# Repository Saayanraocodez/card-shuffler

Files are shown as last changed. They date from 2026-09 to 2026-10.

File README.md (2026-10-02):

# Open card shuffler — 54-slot wheel, 3D-printed, battery powered

A one-button shuffler for one 52–54 card poker deck. Cards are fed one at a
time into a uniformly random empty slot of a 54-slot wheel, then the wheel
is emptied in slot order into a chute. Assigning each card to a random
empty slot is the Fisher–Yates algorithm, so every ordering of the deck is
exactly equally likely when the mechanism does what it is told, and the
firmware checks each insertion with a sensor so that the ways it can fail
are logged, not hidden.

**Status: complete design, unbuilt.** Nothing here has been printed, wired
or tested on hardware. Every performance number is an estimate and is
labelled as such. This machine is not proven, not production-ready and not
guaranteed uniformly random; the validation plan says how to earn those
words.

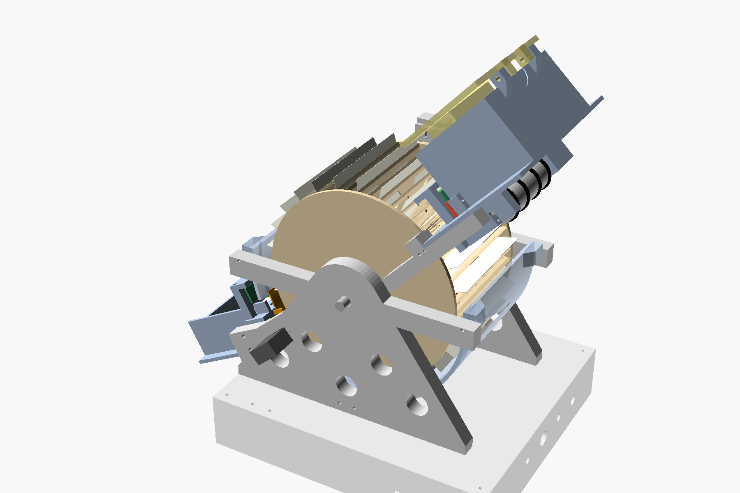
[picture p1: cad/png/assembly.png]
assembly


The first iteration (elevator + separator blades, exact but slower) is kept
complete in `archive/v1-elevator-insertion/`.

## What is here

| Deliverable | Where |
|---|---|
| Mechanism comparison and selection | `docs/01-mechanism-selection.md` |
| Mathematics: uniformity proof, RNG, fault analysis, riffle theory, validation plan | `docs/02-mathematics.md` |
| Simulation and results | `simulation/shuffle_sim.py`, `simulation/results/` |
| Bit-exact RNG reference, physical-test analysis | `simulation/rng_reference.py`, `simulation/analyze_physical.py` |
| Parametric CAD, 24 STL files (print list in `cad/print-settings.md`), views, collision and printability checks | `cad/params.scad`, `cad/shuffler.scad`, `cad/stl/`, `cad/png/`, `cad/check_clearance.sh`, `cad/check_printability.py` |
| Mechanical design document | `docs/03-mechanical-design.md`, `cad/print-settings.md` |
| Electronics, battery, wiring, pins | `docs/04-electronics.md`, `electronics/wiring-diagram.svg` |
| Bill of materials | `docs/05-bom.md`, `electronics/bom.csv` |
| Firmware (ESP32, Arduino) | `firmware/` |
| Assembly, calibration, first use | `docs/06-assembly.md` |
| Operation, maintenance, troubleshooting | `docs/07-operation-maintenance-troubleshooting.md` |
| Verification checklist, prototype plan | `docs/08-verification-checklist.md`, `docs/09-prototype-plan.md` |
| Gaps and unknowns | `docs/10-deliverables-and-gaps.md` |
| Diagrams | `docs/img/` |

## Headline numbers (estimates unless stated)

| | |
|---|---|
| Parts cost, excluding printing | ≈ $114 new; ≈ $96 with a parts drawer; ≈ $88 minimum |
| Cycle time, 52 cards | 40–45 s first build; 28–32 s tuned (target 30 s: within reach, not promised) |
| Randomness | exact uniform in the ideal model (proof §2.2); symmetric slot errors provably harmless with the firmware's map correction; biased errors measured by the machine's own log |
| Size | ≈ 298 × 231 mm footprint (under 12 × 12 in), ≈ 331 mm tall |
| Battery | 3S Li-ion 2200 mAh with BMS; ≈ 0.05 Wh per shuffle |
| Cards | 52–54, thickness 0.22–0.42 mm |

## Quick start for a builder

1. Read `docs/01` and `docs/03`.
2. Follow `docs/09-prototype-plan.md` (feeder first, wheel second).
3. Print with `cad/print-settings.md`, buy from `docs/05`, wire from
   `electronics/wiring-diagram.svg`, flash `firmware/`, calibrate with
   `docs/06` §6.7, verify with `docs/08`.

## Reproducing the analysis

```
pip install numpy scipy
python3 simulation/shuffle_sim.py --quick
python3 simulation/rng_reference.py --selftest
cd firmware/test_host && make run && ./syntax_check.sh
cd cad && ./render.sh && ./check_clearance.sh   # OpenSCAD 2021.01 + xvfb-run
pip install trimesh shapely scipy networkx rtree && python3 check_printability.py
```

## Licence

CC BY 4.0 (documentation, CAD), MIT (code). No warranty; see the safety
notes in `docs/07`.

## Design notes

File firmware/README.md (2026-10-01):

# Firmware (ESP32 DevKitC, Arduino framework) — wheel shuffler

```
shuffler/
  shuffler.ino     state machine: LOAD (random empty slot per card, verified by beam E), UNLOAD (slot order)
  config.h         pins, wheel geometry, speeds, timeouts, calibration record
  platform.*       core 2.x / 3.x shims, hardware RNG with the ADC entropy source
  hardware.*       wheel stepper, shutter servo, three N20 motors, beams B/E/S/X, index, battery, LED, buzzer
  motion.*         wheel home / goto / fin-to-entry / fin-to-exit / scan (every move refused while beam S or X
                   sees a card bridging the wheel); feeder with seat check and nudge; eject with double-card check
  rng.* sha256.* chacha20.*   entropy → SHA-256 → ChaCha20 → rejection sampling (portable)
  shuffle_core.*   empty-slot assignment + output prediction (pure, host-tested)
  storage.*        calibration in NVS
  cli.cpp          serial console (115200): `help`
test_host/         make run (bit-exact test vs simulation/rng_reference.py); ./syntax_check.sh (Arduino mock)
platformio.ini     pio run -e esp32dev
```

## Status

The platform-independent core is unit-tested and bit-exact with the Python
reference. The hardware modules were syntax-checked with `g++` against a
minimal Arduino mock; they have **not** been compiled with the real ESP32
core (toolchain download blocked in the authoring environment). Expect
first-compile fixes and tune every timeout and PWM on hardware.

## Bring-up (see docs/06 §6.7)

Set the TMC2208 Vref to ≈ 1.4 V first (the wheel accelerates at 5000°/s²).
`bat` → `cal vbat`; `beams` → `cal beams`; `home`; `entry 0` + straight edge →
`cal home`; `shutter open/close` → `cal shutter`; `feed` with `entry k`;
`cal entry`; `exit k` + `eject` → `cal exit`; `test fixed 1` + button →
`analyze_physical.py --compare`; `last` → `analyze_physical.py --log`.

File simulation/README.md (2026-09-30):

# Simulation and validation tools

Requirements: Python 3.9+, numpy (scipy optional for exact chi-square p-values).

| File | Purpose |
|---|---|
| `shuffle_sim.py` | Models: exact wheel assignment, wheel neighbour-slot faults (uncorrected and sensor-corrected, symmetric and biased), the archived v1 insertion model and its faults, GSR riffles, a two-hopper riffle machine, bin/shelf shufflers; the statistical test battery; exact Bayer–Diaconis table; small-n total variation. `--quick` ≈ 1 min; `--bd-table` theory only. |
| `rng_reference.py` | Bit-exact reference of the firmware RNG pipeline; `--selftest` prints the test-key slot assignment the firmware's `test ref` must reproduce. |
| `analyze_physical.py` | `--log` (correction tally from the firmware's `last` lines), `--compare` (predicted vs actual deck), `--slots` (statistics on dumped assignments), `--decks` (statistics on recorded physical shuffles). |
| `results/` | Output of the runs quoted in `docs/02-mathematics.md`. |

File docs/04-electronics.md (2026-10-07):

# 4. Electronics and battery power

Wiring diagram: `electronics/wiring-diagram.svg`. BOM: `05-bom.md` /
`electronics/bom.csv`. Firmware: `firmware/shuffler/`. All currents and
energies are **estimates [EST]**.

## 4.1 Architecture

```
 3S Li-ion pack (BMS) ─ fuse 3 A ─ switch ─┬─ VBAT (9.0–12.6 V) ─► TMC2208 ─► NEMA 17 (wheel)
 charge jack ── pack terminals             │                    └► 100k/33k divider ─► GPIO39
                                           └─ buck 5.0 V / 3 A ─┬─► ESP32 DevKitC (VIN)
                                                                ├─► DRV8833 #1 ─► N20 feed, N20 entry nip
                                                                ├─► DRV8833 #2 ─► N20 exit nip
                                                                ├─► MG90S shutter servo
                                                                ├─► 4 × IR LED (NPN switched) + index LED (always on)
                                                                └─► WS2812B
 Sensors (3V3): 4 phototransistors ─► GPIO34/35/32/36 (B, E, S, X); index phototransistor ─► GPIO19; button ─► GPIO21
```

## 4.2 Components

| Function | Part | Notes |
|---|---|---|
| Controller | ESP32 DevKitC V4 (WROOM-32, 30 pins) | hardware RNG, LEDC PWM, ADC1, USB serial |
| Wheel driver | TMC2208 stepstick, standalone, 1/16 | Vref ≈ 1.4 V ≈ 1.0 A RMS on the common 0.11 Ω-sense modules (I_RMS ≈ 0.71 × Vref; check your module); heatsink fitted. A4988 works from a 3S pack |
| Wheel motor | NEMA 17, 1.5–1.7 A class, 40 mm | direct drive through a 5→8 mm coupler onto the M8 rod |
| DC drivers | 2 × DRV8833 modules | 3 channels used |
| Feed roller, entry nip, exit nip | 3 × N20 6 V 300 rpm | feed at ~60 % PWM, nips at ~85–90 % |
| Shutter | MG90S | ±50° swing through an M2 pin |
| Sensors | 5 × 3 mm 940 nm IR LED + phototransistor: beams B (gate), E (card in slot), S (card seated), X (exit), and the index beam | B, E, S, X are read LED-on minus LED-off. E and S run 116 mm tower to tower, so their LEDs get 68 Ω. The index LED is always on |
| Battery | 3S Li-ion 11.1 V 2200–2600 mAh with BMS | 12.6 V 1 A barrel charger |
| 5 V rail | MP1584/LM2596 buck, ≥ 3 A | |
| Indicators | WS2812B pixel, passive piezo | |

## 4.3 ESP32 pin assignment

| GPIO | Name | Dir | Connected to |
|---|---|---|---|
| 25 / 26 / 27 | STEP / DIR / EN | out | TMC2208 (EN active low) |
| 16 / 17 | FEED_IN1 (PWM) / IN2 | out | DRV8833 #1 AIN1/AIN2 → feed roller |
| 4 / 5 | NIPE_IN1 (PWM) / IN2 | out | DRV8833 #1 BIN1/BIN2 → entry nip |
| 15 / 2 | NIPX_IN1 (PWM) / IN2 | out | DRV8833 #2 AIN1/AIN2 → exit nip (strapping pins: the driver inputs do not pull them; keep the DRV asleep at boot) |
| 23 | DRV_SLEEP | out | both DRV8833 nSLEEP |
| 18 | SERVO | out (50 Hz) | shutter MG90S |
| 13 | IR_LED_EN | out | NPN base via 1 kΩ (three emitters) |
| 14 | PIXEL | out | WS2812B DIN via 330 Ω |
| 33 | BUZZER | out (tone) | piezo via 100 Ω |
| 34 / 35 / 32 / 36 | BEAM_B / BEAM_E / BEAM_S / BEAM_X | ADC1 | phototransistor emitters, 10 kΩ pull-downs |
| 39 | VBAT | ADC1 | 100 kΩ / 33 kΩ divider, 100 nF |
| 19 | INDEX | in | index phototransistor emitter, 10 kΩ pull-down (LOW when the tab blocks the beam) |
| 21 | BUTTON | in (pull-up) | start button to GND |
| 22 | DECK_SENSE | in (opt.) | TCRT5000 DO |
| 12, 0 | avoid | | GPIO12 must not be pulled high at boot |

## 4.4 Power budget [EST]

Assumptions: 3S at 11.1 V, buck 85 %, wheel driver disabled between moves
(the shuffle is 40 s: 26 s loading with the wheel moving ~50 % of the time,
12 s unloading with the wheel moving ~40 %).

| Load | Condition | Power | Duty | Average |
|---|---|---|---|---|
| ESP32 | always | 0.40 W | 100 % | 0.40 W |
| IR LEDs (4 pulsed, ~160 mA while on) + index LED | polling | 0.45 W | 100 % | 0.45 W |
| Pixel | | 0.10 W | 100 % | 0.10 W |
| NEMA 17 at 1.0 A RMS | moving | 5.5 W | 45 % | 2.5 W |
| N20 feed + entry nip | 0.5 s per card during loading | 1.5 W | 45 % (of the load phase ≈ 30 % of total) | 0.45 W |
| N20 exit nip | 0.15 s per card during unloading | 0.75 W | 20 % of total | 0.15 W |
| Servo | holding open during unload | 0.5 W | 30 % | 0.15 W |
| **Total from the pack while shuffling** | | | | **≈ 4.7 W** |
| Idle | | | | ≈ 0.8 W |

* Energy per 40 s shuffle ≈ 190 J ≈ **0.05 Wh**.
* Usable pack energy ≈ 19.5 Wh → **≈ 390 shuffles** back-to-back (upper bound).
* A 4-hour evening with 40 shuffles ≈ 2 + 3.2 = 5.2 Wh → about 3–4 evenings per charge.

## 4.5 Peak and stall currents [EST]

| Item | Peak / stall |
|---|---|
| NEMA 17 (driver-limited) | 1.0 A RMS, 1.4 A peak per phase; at a 12 V bus ≈ 0.6 A from the pack during acceleration. Needed: ≈ 13 N·cm at 5000°/s²; a 17HS4401 gives ≈ 25–30 N·cm at 1 A, so the margin is about 2× |
| MG90S | ≈ 0.7 A at 5 V stall (shutter travel is unobstructed) |
| N20 ×3 | ≈ 0.8–1.0 A each at 5 V stall; at most two run at once |
| Worst case simultaneous | ≈ 5.5 W + 5 V × 2.7 A / 0.85 ≈ 21 W ≈ **2 A from the pack** |

3 A fuse, 3 A buck, pack BMS ≥ 5 A.

## 4.6 Battery, charging, low-battery behaviour

Unchanged from v1 (`archive/v1-elevator-insertion/docs/04-electronics.md`
§4.6):
* **Pack:** 3S1P 18650 pack with integrated protection, Velcro-strapped on
  a foam pad in the front base box.
* **Charging:** 5.5 × 2.1 mm charge jack wired to the pack terminals,
  upstream of the switch.
* **Thresholds:** warning below 9.9 V, refuse to start below 9.6 V, abort
  below 9.3 V. When the firmware aborts mid-load, it finishes the current
  card and unloads the cards already in the wheel into the chute. The
  remaining cards stay in the hopper. Charge, put all cards back in the
  hopper and shuffle again.
* **Options:** the USB-C PD power-bank option and the 2S option are as in
  v1.

## 4.7 Safety and shutdown

* The wheel cannot drop anything on power loss: cards sit in slots, the
  shroud holds the lower half, and the shutter's servo is unpowered when
  idle with the shutter closed by its own friction (add the return spring
  post if the shutter drifts).
* Any jam stops all motors within one sensor poll and waits for the
  button. Holding the button for 3 s runs "unload all": close the
  shutter, home, scan, bring the first occupied slot to the exit, open
  the shutter, then empty every occupied slot into the chute.
* **Interlock:** the wheel refuses to move while beam S (a card bridging
  the feeder and a slot) or beam X (a card in the exit nip) is blocked. A
  half-inserted card can therefore never be dragged into the frame.
* The wheel is enclosed by the towers, shroud, feeder and chute; the open
  areas are the hopper (under the lid) and the chute. Fingers cannot reach
  the wheel rim except through the chute end when the shutter is open; the
  wheel moves at up to 360°/s but has little inertia and the stepper stalls
  at about 20 N·cm.

## 4.8 Perfboard

70 × 50 mm perfboard: ESP32 on female headers, TMC2208 and two DRV8833 on
female headers, buck module, NPN with a 470 Ω base resistor, LED resistors
(150 Ω for B and X, 68 Ω for E and S, 330 Ω for the always-on index LED),
five 10 kΩ pull-downs, divider, capacitors (100 µF on TMC VM, 100 µF on
each DRV VM, 470 µF on 5 V), JST-XH headers J1–J17 (see the wiring
diagram). Mount in the front base box with
the ESP32's USB reachable through the side cut-out.

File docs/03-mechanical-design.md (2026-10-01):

# 3. Mechanical design and printable parts

Source of truth: `cad/params.scad` (every dimension) and `cad/shuffler.scad`
(every part, assembly, exploded and section views). STLs are in `cad/stl/`
and views in `cad/png/`. Both are regenerated by `cad/render.sh` (OpenSCAD
2021.01). `cad/check_clearance.sh` checks that no fixed part enters the
volume swept by the wheel and its cards, and that neighbouring parts do not
overlap (17 checks, all passing).

| View | File |
|---|---|
| Assembly | `cad/png/assembly.png` |
| Exploded | `cad/png/exploded.png` |
| Section at the centreline | `cad/png/section.png`, annotated `docs/img/mechanism-section.svg` |
| Front (looking along the axis) | `cad/png/front.png` |
| Wheel module exploded | `cad/png/wheel_exploded.png` |
| Feeder / exit modules exploded | `cad/png/feeder_exploded.png`, `cad/png/exit_exploded.png` |
| Load / unload sequence | `docs/img/insertion-sequence.svg` |

## 3.1 Frame, layout and the clearance rule

The wheel axis is horizontal (Y). Angles are measured in the vertical XZ
plane from +X (3 o'clock), counter-clockwise. Fin k is a radial plate whose
counter-clockwise face lies on the radial plane at (wheel angle + k · 6.667°).
Slot k is the space between fin k and fin k+1.

**Clearance rule.** Whenever the wheel turns, the seated cards sweep every
point with radius ≤ 85.5 mm and |Y| ≤ 46 mm, including card play in the cage.
The discs sweep r ≤ 77.5 at |Y| 46–49, and the index tab sweeps r 66–76 at
Y 49–53. Nothing fixed may enter these volumes, with at least 0.4 mm to
spare. Every fixed part at the entry and exit therefore starts outside
r 86.

| | mm |
|---|---|
| Footprint, overall | ≈ 298 × 231 (11.7 × 9.1 in, under the 12 × 12 in limit) |
| Base boxes | 233 × 210 × 45 |
| Height | ≈ 331 (axis 145 above the table, hopper lid top 186 above the axis) |
| Wheel outer diameter (fin tips / discs) | 155 |
| Shroud outer diameter | 183 |
| Mass, printed parts | ≈ 1.25 kg [EST] (wheel ≈ 375 g) |

## 3.2 The wheel

| Feature | Value | Reason |
|---|---|---|
| Slots | 54 | 52-card deck plus jokers; two slots stay empty |
| Hub tube outer radius (card stop) | 22 | smallest hub that keeps the slot at the hub ≥ 1.1 mm |
| Seated card: inner / outer edge | 22 / 85.5 | card 63.5 mm radial |
| Fin tips and disc radius | 77.5 | cards overhang 8 mm; the entry beam sees the overhang |
| Fin thickness | 1.4, chamfered to a point over the last 2.5 mm | an incoming card rides onto the fin face instead of hitting its end |
| Slot width | 1.16 at the hub, 7.6 at the tip | funnel |
| Fin windows | 17 × 30 and 19 × 30 mm per fin, pointed at the +Y end | lighter fins; the points let the window tops print without bridging. Inertia ≈ 1.45 × 10⁻³ kg·m² with cards [EST] |
| Discs | 3 mm. −Y disc solid (it is the first layers on the bed); +Y disc spoked, ring r 62–77.5 | |
| Hub | tube r 20–22 with a bore tube and 6 ribs inside | the +Y disc bridges ≤ 14 mm between the ribs |
| Index tab | +Y disc face, r 66–76, Y 49–53, at 90° | inside the rim, so it never crosses the entry beams |
| Bore | 8.6 for an M8 threaded rod, clamped by nyloc nuts | +Y boss on the wheel; the −Y boss is the separate `hub_spacer` |

Printing: axis vertical, the solid −Y disc on the bed, 104 mm tall, about
24 h, PETG. The top disc bridges the ≤ 7.6 mm slot widths.

## 3.3 Retention: shroud and shutter

In the lower half, gravity pulls cards outward. A fixed shroud stops them
after 3 mm of travel: inner radius 88.5, 3 mm thick, in two segments from
172° to 270° and from 270° to 368°. It runs from tower face to tower face
(116 mm), so each segment prints standing on a full edge. The −Y edge is
cut back to 92 mm wide where the shutter's drive tab travels (202°–236.5°).
Across the exit window only a strap at |Y| 47–58 remains, outside the
card width. The card edge then slides
on smooth PETG as the wheel turns.

The exit window (202°–214°) is closed during loading by a **shutter blade
on the inside of the shroud**. The blade is 1.2 mm thick at r 87.0–88.2 and
spans 199.4°–216.6°. Its ends taper to 0.4 mm, so a card edge riding on the
shroud ramps onto the blade and off again, and no edge is exposed for a
card to catch. To open, an MG90S servo in a pocket in the −Y tower slides
the blade 17.5° counter-clockwise along the shroud's inner surface. The
servo drives through an M2 pin on an 18 mm horn into a radial slot in the
blade's drive tab, which sits beside the shroud end at |Y| 46.5–48.5,
outside the card width. Gravity keeps the blade against the shroud
everywhere it travels. With the window open, a card at 208° slides out
under 0.47 g into the exit nip.

## 3.4 Feeder (entry at 50°)

Cards travel along their 63.5 mm edge. The hopper interior is 65 (radial)
by 91 (axial), and its floor is the plane of the entry fin, 46.7° from
horizontal. The deck slides against the gate under 0.73 g, so lid ballast
matters only for the last cards.

| Feature | r (mm) | Note |
|---|---|---|
| Beam E, "card in the slot" | 81.5 | oblique, from the +Y tower (4 mm above the card plane) to the −Y tower (4 mm below). It crosses the plane of the card in the target slot near the centre, so that card blocks it completely. Neighbour cards are 9.5 mm away |
| Seated card outer edge | 85.5 | |
| Beam S, "card seated" | 86.8 | oblique like beam E. It is blocked only while a card still bridges the plate and the slot |
| Entry nip axis (Ø16 roller, 4 O-rings 10 × 3) | 96 | nearest point r 88.3; the deck plate starts at the nip (r 88.5) |
| Idler wheels | over the outer O-rings, Y ±27 | spring-loaded arm, pivot at r 107.75; pen springs bear on a `spring_bar` screwed across the pivot posts |
| Beam B (gate beam) | 106.5 | detector in the idler arm's boss, emitter in the plate |
| Gate lip | 118 | slotted clamp, feeler gauge, 0.45 mm nominal |
| Feed roller axis (Ø27, 4 O-rings 20 × 3.5) | 129.5 | crown 0.7 mm above the floor |
| Hopper | 118–183 | back wall to 186; lid hinge on the back wall |

The nip pushes the card until 10.5 mm before the hub. The card bridges
11 mm from the nip to the fin tips, then slides down the fin face under
0.73 g and stops on the hub tube. The firmware sets the fin 0.3° below the
card plane, so the card meets the fin's chamfered lead-in rather than its
end. The rollers are 64 mm long, so each N20 motor fits between the roller
end and the tower (Y 32.5–56.5). The next card is pre-staged 10 mm past the
gate. The gate geometry and thickness range are unchanged: t_max < gap <
2 t_min, adjustable 0.30–0.60 mm.

## 3.5 Exit (205°) and chute

| Feature | r (mm) | Note |
|---|---|---|
| Shroud window | 202°–214° | covered by the shutter blade while loading |
| Exit nip axis (Ø16 roller) | 100.5 | everything at the exit starts at local r ≥ 95.5, clear of the shutter tab |
| Beam X | 111 | detector in the exit idler arm (the same part as the entry arm) |
| Chute floor | 109.5–182.5, 28 mm below the exit plane | inclined 28°; a 54-card thick deck stays below the exit plane. It sits between the towers (\|Y\| ≤ 57.5) |
| Chute mounting | nip housing at r 111 | 2 horizontal M3 × 20 per side, through the towers' chute cheeks into the housing |
| End wall | 182.5 | felt-lined; the pile starts 8 mm past beam X |

The deck forms against the end wall. The chute end overhangs the rear base
and clears the table by about 30 mm.

## 3.6 Towers, drive, base

* **Towers.** Two 12 mm plates at |Y| = 58–70, printed flat with the outer
  face down (213 × 198 mm, fits a 220 mm bed). Each has:
  * a 608ZZ bearing pocket;
  * a foot on the base;
  * a crossbar carrying the shroud tabs;
  * an arm under the feeder deck with two vertical M3 holes (the deck
    screws down into it);
  * a chute cheek with two horizontal holes (the chute screws to it from
    outside);
  * a 4 mm inner-face boss holding the beam E and beam S emitters (+Y) or
    detectors (−Y).

  The +Y tower also has a post at 12 o'clock for the index bracket and
  four counterbored holes for the motor bolts. The separate `motor_mount`
  (a hollow Ø50 × 28 standoff holding the coupler) sits on its outer face;
  four M3 × 40 bolts go from the tower's inner face through both into the
  NEMA 17. The −Y tower has the shutter servo pocket and horn recess.
* **Drive.** NEMA 17 → 5–8 mm flexible coupler → M8 threaded rod, cut to
  165 mm, clamped to the wheel with nyloc nuts. The rod turns in the
  bearings: wrap one layer of tape on the thread at each bearing seat so it
  does not rattle. Direct drive, 3200 µsteps per revolution, 0.11° per
  microstep.
* **Base.** Front and rear boxes (193 and 40 mm long, 210 wide, 45 tall)
  with bottom covers. The tower feet screw to the base top, so the axis is
  100 mm above it. The battery and perfboard go inside, and the panel is on
  the front face.

## 3.7 Printed parts

The full list, with quantities, sizes, orientation, settings and
post-processing, is `cad/print-settings.md`: **24 STL files, 30 printed
pieces** (2 × `roller_nip`, 2 × `idler_arm`, 4 × `idler_wheel`,
2 × `spring_bar`). Every STL rests on Z = 0 in its print orientation, and
`cad/check_printability.py` confirms that each one is a closed solid that
fits a 220 mm bed and prints without supports. Total ≈ 1.25 kg [EST]
(≈ 0.9 kg PETG, ≈ 0.35 kg PLA).

## 3.8 Tolerances and adjustment points

| Fit | Nominal | Adjustment |
|---|---|---|
| Wheel position at the entry | ±0.7° (±1 mm at the mouth) | `cal home`, `cal entry` (default −0.3°), `cal exit` |
| Slot mouth | 7.6 mm at the tip, 1.16 at the hub | none; the funnel self-guides |
| Seated card edge to nearest fixed part | ≥ 1.3 mm (beam S line) | none |
| Card in the cage (axial) | 92 for 88.9 | none |
| Shroud to card edge | 3 mm | shim the shroud tabs if cards rub |
| Shutter blade to shroud | 0.3 mm | sand the blade's outer face |
| Gate gap | 0.45 | feeler gauge (the critical adjustment) |
| Idler wheels to roller O-rings | O-ring contact at the card plane | pen springs; add a washer for more force |
| Beam thresholds | auto | `cal beams` |
| Bearing pockets | 22.2 for 608ZZ | press fit |

Print variation is absorbed by the funnel-shaped slot mouths, the firmware
trims and the feeler-gauge gate. The only printed dimension that affects
randomness is the fin pitch. That is a division of the circle and cannot
drift.

## 3.9 Card protection

| Risk | Response |
|---|---|
| Scratches | rolling contact in the nips; cards slide face-on over smooth fins; rounded gate lip; felt on the chute end wall and under the lid boss |
| Edge wear | the hub stop is a 2 mm PETG wall; in the lower half the edges ride on the shroud and on the tapered shutter; a felt strip inside the shroud is an optional upgrade |
| Bent corners | straight radial entry onto a chamfered fin; the wheel cannot turn while beam S or beam X sees a card half in a slot |
| Excessive pressure | nips about 2 N; lid about 0.6 N |
| Exposed faces | face down under the lid; between fins inside the cage; only the top card's back shows in the chute |
| Double feed | gate at 1.3–1.5 × card thickness; beam-B and beam-X block-time checks; end count |
| Cards flying out | shroud and shutter in the lower half; gravity and a 360°/s speed limit in the open upper half |

## 3.10 Things a builder may want to change

`entry_slot_ang` (steeper hopper), `exit_slot_ang` (steeper exit, longer
chute), `fin_t`, `n_slots` (keep `N_SLOTS_HW` in the firmware equal),
`roller_len` (the N20 must still fit inside the towers). After any change,
run `cad/check_clearance.sh`.

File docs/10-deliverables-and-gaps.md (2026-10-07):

# 10. Deliverables, what could not be produced, open unknowns

## 10.1 Delivered

| Requested | Delivered |
|---|---|
| Mechanism comparison, selection, tradeoffs | `01-mechanism-selection.md` (wheel selected; v1 elevator-insertion and the two-well variant compared) |
| Honest cycle-time estimate | `01` §1.6: 40–45 s first build, 28–32 s tuned |
| Mathematics: proofs, RNG, fault analysis, riffle theory, validation plan | `02-mathematics.md` |
| Simulation code and results | `simulation/shuffle_sim.py`, `simulation/results/` (wheel, corrected/uncorrected faults, v1 faults, riffles, bins) |
| Dimensioned mechanical design, parametric CAD, printable files, exploded views, print settings, tolerances | `03-mechanical-design.md`, `cad/params.scad`, `cad/shuffler.scad`, 24 STL files in `cad/stl/`, views in `cad/png/`, print list `cad/print-settings.md`, collision checks `cad/check_clearance.sh`, print checks `cad/check_printability.py` |
| Electronics, battery, wiring, BOM | `04-electronics.md`, `electronics/wiring-diagram.svg`, `05-bom.md`, `electronics/bom.csv` |
| Complete firmware | `firmware/shuffler/` (RNG core host-tested bit-exact; hardware modules syntax-checked against a mock) |
| Assembly, calibration, first-use checks | `06-assembly.md` |
| Operation, maintenance, troubleshooting | `07-…md` |
| Verification checklist, prototype plan | `08`, `09` |
| Previous design for comparison | `archive/v1-elevator-insertion/` (complete, self-contained) |

## 10.2 Not produced, or produced with limits

* **No physical build, no measurements.** Every [EST] value is an estimate.
  What can be claimed today: the algorithm is uniform (proof); the firmware
  RNG core is bit-exact with the reference and passes its tests; the CAD
  passes 17 automated collision checks against the wheel's swept volume
  and between neighbouring parts; the fault models are simulated. What cannot: feeding reliability,
  slot-entry and slide-out reliability, the cycle time, battery life.
* **ESP32 compile.** The Espressif toolchain could not be downloaded in the
  authoring environment (the proxy blocks the PlatformIO registry, GitHub
  archives and dl.espressif.com). The hardware modules were syntax-checked
  with `g++` against a minimal Arduino mock (`firmware/test_host/mock/`,
  `firmware/test_host/syntax_check.sh`), which catches typos and type errors but not API
  mismatches with the real core. Budget an hour for first-compile fixes.
* **3MF, STEP, PCB files** not generated (OpenSCAD 2021 exports STL).
* **Supplier verification** partial: main parts checked against listings in
  September 2026 (ESP32, TMC2208, MG90S, N20, DRV8833, chargers, IR parts,
  lead-screw kits with couplers); the 3S pack, NEMA 17 single price, index
  module and small hardware are typical prices.
* **Renders** are OpenSCAD previews, not photographs.

## 10.3 Critical unknowns to retire in Stages 1–3

1. Single-card separation with a lip gate on a 50° hopper (the deck presses
   harder on the gate than in v1).
2. Card entry into the tapered slot at 50°: whether cards ever stop short or
   bounce back, and the symmetric/biased split of neighbour-slot errors.
3. Card slide-out at 28° below horizontal into the exit nip; cards clinging
   to the fin by static.
4. Card edges riding on the shroud in the lower half: wear over hundreds of
   decks.
5. Wheel index time and stall margin with the real wheel mass.
6. `bootloader_random_enable()` interaction with `analogRead` on the
   installed core (firmware re-initialises the ADC after seeding).
7. The inner shutter blade (1.2 mm PETG) sliding on the shroud: friction,
   and whether card edges ride its 0.8 mm ramps smoothly.
8. The oblique beams E and S: signal margin over 116 mm with a 1.2 mm
   aperture, and how cleanly beam S separates "seated" (edge at r 85.5)
   from "bridging" (card across r 86.8).

## 10.4 Review log (design review after the wheel redesign)

Mistakes found and fixed in the review:

* **Speed:** firmware acceleration 900°/s² gave 0.6 s per index, not the
  0.25 s the docs claimed. It is now 5000°/s² at about 1 A RMS. The quoted
  torque had also been 10× too high.
* **Entry:** seated cards overlapped the feeder plate and the beam-E
  bridge by 3.5 mm. Every wheel move would have dragged cards into them.
  The plate now starts at the nip, and beams E and S run obliquely between
  the towers.
* **Exit:** the outside sliding shutter let cards drop 3.5 mm into the
  window and snag its edge. It is now a ramped blade on the inside of the
  shroud.
* **Feeder motors:** the entry N20 motors passed through the motor-side
  tower. The rollers are now 64 mm long and the motors fit inside.
* **Idlers:** the idler wheels missed the roller O-rings. They now sit over
  the outer O-rings.
* **Missing mounts:** beam B's detector had no mount; it is now in the
  idler arm's boss. The idler springs had nothing to push on; spring
  crossbars were added. The index bracket screws went into empty space
  above the tower; a post was added. The slotted index module could not
  straddle the tab; it is now a radial LED and phototransistor pair.
* **Pivot conflicts:** the gate block flange collided with the idler pivot.
  The gate moved 7 mm outward. The idler ears sat on the rails and could
  not pivot.
* **Mismatched holes:** the tower-to-deck and tower-to-chute screw holes
  were perpendicular to their mating holes.
* **Placement:** the mechanism was placed 45 mm too low, sinking into the
  base. The chute passed through the rear base box.
* **Footprint:** it was 320 mm, over the 12 in (305 mm) limit. It is now
  about 298 × 231 mm.
* **Firmware safety:** nothing stopped the wheel turning with a card half
  in a slot. There is now a beam S / beam X interlock on every move.
  There was also no check that the target slot was empty before feeding.
  The firmware now re-homes, then stops with ERROR 11. A failed eject
  carried on rotating; it now stops. The exit has a block-time double-card
  check.
* **Docs:** the low-battery abort description did not match the firmware.
* **Unload order:** the firmware opened the shutter before the first unload
  move, with the wheel still at the last entry position. Two cards rested
  over the window there and slid out against the stopped nip, unseen by
  beam X, and the move to slot 0 (up to 180°) swept 11–14 more cards across
  the open window, the snag the inner blade was meant to prevent. The
  wheel now brings the first occupied slot to the exit with the shutter
  closed, then opens it. With a full deck every later move carries only
  empty slots past the window. "Unload all" also closes the shutter before
  homing, since it can follow an ERROR 9 with the shutter still open. The
  bench test (6.5) and C8 (6.7) now move first and open second. Still
  open: on a wheel holding a few cards, a run of more than 27 empty slots
  makes the move to the next card take the short way back over the
  window, carrying any later card across it.

## 10.4.1 Print-readiness sweep

A slicer-style check (`cad/check_printability.py`: slices every STL at
0.2 mm and flags anything printed over air) and new mating-part collision
checks found:

* **Towers** printed standing on their 4 mm beam bosses, with the whole
  plate 4 mm in the air. They now print outer face down; the motor
  standoff became the separate `motor_mount`, bolted through with 4 × M3 ×
  40. A plate was added behind the beam boss, which overhung the tower edge.
* **Chute vs towers (assembly clash):** the chute floor ran through both
  tower plates (≈ 1.9 cm³ overlap), and one chute screw hole was sealed
  inside the tower. The floor now sits between the towers and screws to
  new tower cheeks from the side.
* **Wheel** printed on a hub boss, with the 155 mm disc 6 mm in the air.
  The −Y boss is now the separate `hub_spacer`, the −Y disc is solid, the
  hub has internal ribs, and the fin windows are pointed so their tops
  need no bridging. The wheel is heavier (≈ 375 g; inertia ≈ 1.45 × 10⁻³
  kg·m² with cards, ≈ 13 N·cm peak at 5000°/s²).
* **Shroud A** was cut in two by the exit window, and both shrouds stood
  on their tab feet only, with the arc 12 mm in the air. The arc now runs
  tower to tower, with a strap across the window and 45° tab gussets.
* **Feeder deck:** the hinge knuckles were loose, unattached bodies, and
  the middle one sat over the finger recess. The rails touched the gate
  bosses along a single edge, so the mesh was not watertight. The gate
  wall was a 91 mm bridge. Now there are two gusseted knuckles, window
  jambs, and three cut-away print ribs.
* **Spring crossbars** (deck and chute) were 110 mm bridges. They are now
  a separate `spring_bar`, ×2.
* **Lid** printed on its ballast box, with the plate overhanging it, and
  had a sealed cavity. The AA ballast now drops into pockets in the
  pressure boss, and the lid prints top face down.
* **Rollers** stood on their 4 mm stub axles; they now stand on the D-bore
  end. The **index bracket** printed with 7 mm ledges; it now prints back
  plate down. The **gate block's** top overhung its flange; it is tapered.
  The exit +Y rail hung over the motor pocket and was removed.
* **Counts:** 24 files, 30 pieces. The two nips use 2 × `roller_nip`, and
  the 2 × `idler_arm` carry 4 × `idler_wheel`. Filament is ≈ 1.25 kg, not
  900 g.

## 10.5 Environment record

* OpenSCAD 2021.01 rendered all 24 STL files with no warnings; `cad/check_clearance.sh`: 19 OK + 4 face contacts, no collisions (`cad/clearance.log`); `cad/check_printability.py`: all 24 parts OK (`cad/printability.log`).
* Simulation: `simulation/results/full_results.txt` and
  `simulation/results/corrected_runs.txt` (numpy 2.4, scipy 1.17).
* Host test: all pass. Syntax check: pass (two style warnings fixed).
* ESP32 compile: not possible here (see above).

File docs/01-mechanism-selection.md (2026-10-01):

# 1. Mechanism selection

This document compares the feasible ways to shuffle one 52–54 card poker
deck with a machine a hobbyist can print and wire, and explains why this
project uses a **54-slot wheel with random slot assignment** (a horizontal-
axis "rolodex" into which each card is pushed at a uniformly random empty
slot, then emptied in slot order). The first iteration of this project used
elevator-insertion with separator blades; it is kept in
`archive/v1-elevator-insertion/` and is compared below.

Everything here is a design analysis. Nothing has been built; the speed
and reliability numbers are engineering estimates and are labelled as such.

## 1.1 Requirements

| Requirement | Target |
|---|---|
| Deck | 52 cards, 54 if practical (poker size 63.5 × 88.9 mm) |
| Card thickness | 0.25–0.35 mm standard; 0.22–0.42 mm accepted (custom decks) |
| Operation | Load, one button, collect |
| Cycle time | < 30 s target; honest estimate required |
| Randomness | Measurably close to uniform over all 52! orders |
| Card safety | No scratches, bent corners, exposed faces |
| Power | Rechargeable protected battery |
| Cost | < $130 excluding printing |
| Size | Footprint under 12 × 12 in (305 × 305 mm); noise not a concern |

## 1.2 Candidates

**A. Two-hopper riffle machine** (the $20 consumer shuffler). Fast per pass
(3–5 s) but a machine riffle is far from the Gilbert–Shannon–Reeds model:
the cut is always near 26/26 and the rollers alternate almost perfectly, so
one pass leaves the deck with exactly 2 rising sequences. Seven or more
passes with manual re-splitting are needed; automating the re-split is the
hard part of any shuffler. Fails "one button".

**B. Random-bin (shelf) routing.** One feeder, a diverter, N bins stacked in
order. One pass is the inverse of an N-riffle; with N = 8 it takes 4 passes
to reach total-variation distance 0.01, and recombining the bins needs
either the user or a complex mechanism (Diaconis, Fulman & Holmes 2013
analysed a real 10-shelf casino machine and showed one pass is exploitable).

**C. Single-card random-gap insertion (elevator + blades)** — the archived
v1 design. Exact Fisher–Yates; every card needs its own serial
elevator/blade cycle of 1.0–1.4 s, and the blade must enter a chosen card
boundary to ±0.15 mm. Estimated 70–80 s per deck, 45–50 s tuned.

**D. Two parallel insertion wells** — v1 with a diverter and a second well.
Exactly uniform when the A/B assignment is exchangeable (proof in
`02-mathematics.md` §2.6). About 35–40 s, +$45, and the user stacks two half
decks.

**E. 54-slot wheel (random slot assignment) — selected.** A horizontal-axis
cage of 54 radial fins. Each card is pushed radially into a uniformly
chosen empty slot at the upper-right entry position (it slides down the fin
face under gravity and seats against the hub); when the hopper is empty a
shutter in the lower shroud opens and, as the wheel steps through the slots
in order, each card slides out under gravity into a roller nip that pulls
it into a tilted output chute. Assigning card i to a uniformly random empty
slot is the Fisher–Yates "draw from the remaining set" step, so the output
order (slot order) is exactly uniform (proof in `02-mathematics.md`).

| Criterion | A. Riffle | B. Bins | C. v1 insertion | D. Dual well | **E. Wheel** |
|---|---|---|---|---|---|
| Randomness per press | 1 | 2 | 5 | 5 | **5** |
| Speed (est.) | 5 (5 s ×7 manual) | 3 | 2 (70 s) | 3 (38 s) | **4 (35–45 s; ~30 s tuned)** |
| Precision demanded of the build | 4 | 4 | 1 (±0.15 mm) | 1 | **4 (±1 mm)** |
| Cost | 5 | 3 | 3 | 2 | **3** |
| Footprint | 4 | 3 | 4 | 2 | **3 (298 × 231 mm)** |
| Mechanical complexity | 4 | 2 | 3 | 2 | **4** |
| Card wear | 2 | 4 | 5 | 5 | **4** |
| One-button | 1 | 2 | 5 | 4 | **5** |
| **Weighted (randomness ×3, precision ×2, one-button ×2)** | 31 | 33 | 42 | 41 | **52** |

## 1.3 Why the wheel wins

* **No fine tolerance.** A slot mouth is 8 mm wide at the rim and tapers
  to 1.2 mm at the hub, so the wheel only has to be positioned to about
  ±1 mm (±0.7°). A direct-drive NEMA 17 at 1/16 microstepping resolves
  0.11°. The v1 design needed ±0.15 mm on a blade edge.
* **Exact algorithm, no gap opening.** Every card has its own slot; nothing
  is inserted into a stack.
* **Fewer actuators.** One stepper, three small DC motors (feed, entry nip,
  exit nip), one servo (shutter). v1 needed two servos, blades, a lead
  screw and guide rods.
* **Speed.** Loading is limited by the wheel index (average 90°, ≈0.25 s)
  plus the card push (≈0.25 s); unloading is a step-and-pull of 6.7° per
  card. Estimates in §1.6.
* **Self-checking.** A beam at the entry sees whether the card is in the
  slot just loaded; a card that lands one slot off is found by looking at
  the neighbours and the firmware corrects its map (§2.4 shows this keeps
  the output exactly uniform when the error is symmetric).

## 1.4 Architecture

```
                         hopper (deck face down, 50° slope, lid)
                        /  feed roller → gate → entry nip → beam E
                       /
      +Y tower ──── WHEEL: 54 radial fins, cards lie flat on a fin ──── −Y tower
      NEMA 17 ◄── M8 rod, 608 bearings ──►  index tab / sensor at 12 o'clock
                       \
   shroud (lower half)  \ exit window at 8 o'clock, servo shutter
                         \ exit nip → beam X → tilted chute (output deck)
```

* **Wheel module**: cage (Ø155 mm, 98 mm wide, hub tube Ø44, fins from
  r 22 to 77.5), two towers with 608 bearings on an M8 rod, NEMA 17 on the
  +Y tower through a flexible coupler, two shroud segments (lower half),
  a shutter blade sliding on the inside of the shroud, index bracket.
* **Feeder module** (at 50°): the v1 hopper turned so cards travel along
  their 63.5 mm edge. It has a feed roller (Ø27), an adjustable gate, an
  entry nip (Ø16) with spring idlers, gate beam B and a weighted lid. The
  "card in slot" beam E and "card seated" beam S run between the towers.
* **Exit module** (at 205°): exit window in the shroud, exit nip (Ø16)
  with idlers, exit beam X, and a chute inclined 28° with a felt-lined end
  wall. The deck is lifted out of the open chute.
* **Base**: two boxes (front/rear) holding the battery and the perfboard,
  with the panel (button, LED, switch, charge jack).
* **Controller**: ESP32 DevKitC; TMC2208 for the wheel, two DRV8833 for the
  three N20 motors; ChaCha20 DRBG seeded from the hardware RNG.

## 1.5 Card handling in the wheel

Cards lie flat on a fin at the entry (fin at 46.7° above horizontal). The
entry nip pushes each card until it is 10.5 mm from the hub, and the card
slides the rest of the way down the fin face under gravity. In the upper
half of the wheel, gravity keeps each card seated against the hub. In the
lower half, the card slides outward by up to 3 mm onto the fixed shroud.
Fins are 1.4 mm thick, lightened with windows and chamfered at the tip.

A seated card's outer edge is at r 85.5. Every fixed part near the wheel
stays outside r 86, so turning the wheel never drags a card into anything.
`cad/check_clearance.sh` verifies this. The card overhangs the fin tips by
8 mm, which lets the oblique beam E see it. At the exit (fin at 208.3°, 28°
below horizontal), the shutter blade slides away. The card then slides out
under gravity into the running nip and is pulled into the chute.

## 1.6 Cycle time: honest estimate

| Phase | Per card | Basis |
|---|---|---|
| Wheel index to a random empty slot | 0.25 s | mean 90° shortest path at 5000°/s² and 360°/s max. Inertia with cards ≈ 1.45 × 10⁻³ kg·m² [EST], so about 13 N·cm peak. The driver must be set to ≈ 1.0 A RMS. At the earlier 900°/s² setting the mean index was 0.6 s and the shuffle ≈ 60–65 s |
| Card push from the pre-staged gate into the slot (85 mm at 0.3 m/s) | 0.30 s | overlaps ~0.05 s with the index |
| **Load, 52 cards** | **≈ 26 s** | |
| Unload: step 6.7° + pull 63.5 mm at 0.5 m/s + settle | 0.22 s | 52 occupied slots |
| **Unload** | **≈ 12 s** | |
| Homing, start-of-run scan, shutter | ≈ 6 s | the scan (one revolution reading beam E) can be disabled |
| **Total, first build** | **≈ 40–45 s** | |
| Tuned (faster stepper current, 0.15 s index, 0.15 s pull, no scan) | ≈ 28–32 s | |

The 30 s target is within reach after tuning but should not be promised
before a build. The v1 design could not get below ~45 s.

## 1.7 Tradeoffs accepted

* The wheel is the largest printed part (155 × 162 × 110 mm, ~24 h print).
* Cards' edges touch the shroud in the lower half (smooth PETG) and their
  faces slide on the fins; both are gentler than a riffle.
* Two extra sensors and one extra DC motor compared with v1, in exchange
  for removing the blades, the lead screw, the rods and one servo.
* Height ≈ 331 mm (the hopper stands at 50° on top of a 145 mm axis).

## References

* D. Bayer, P. Diaconis, "Trailing the dovetail shuffle to its lair",
  *Annals of Applied Probability* 2(2), 1992, pp. 294–313.
* P. Diaconis, J. Fulman, S. Holmes, "Analysis of casino shelf shuffling
  machines", *Annals of Applied Probability* 23(4), 2013, pp. 1692–1720.
* Shuffle Master elevator-insertion patents (US 8,538,155 and family) for
  the v1 comparison; Shuffle Tech ST-1000 user reports (80–100 s per deck).

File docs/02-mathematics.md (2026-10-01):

# 2. Mathematics of the shuffle

Statements are labelled **[PROOF]** (holds for the idealised model), **[SIM]**
(Monte-Carlo, `simulation/shuffle_sim.py`, results in `simulation/results/`),
**[EST]** (engineering estimate) or **[PHYS]** (measured on hardware —
**none yet; the machine has not been built**).

## 2.1 What "random" has to mean here

The output is an ordering π of the deck, one of n! (52! ≈ 8.07 × 10⁶⁷).
The goal is **uniformity**: P(output = π) = 1/n! for every π, independent of
the input order and of anything a player can observe. Three different
things are needed and must not be confused:

1. **Physical entropy** — unpredictable bits (≥ log₂ 52! = 225.6 per deck).
2. **Pseudorandom control** — a deterministic generator expanding a seed
   into the slot choices. Without a fresh physical seed it repeats.
3. **A uniform output law** — a property of algorithm + mechanism. Random
   motor timings do not create it; only an algorithm whose output law is
   provably uniform, executed faithfully, does.

## 2.2 The algorithm the wheel executes: random empty-slot assignment

The wheel has N = 54 slots. Cards are fed in input order c₀ (bottom) …
c₅₁. For card i the firmware draws a uniformly random slot among the slots
it knows to be empty and places the card there. At the end the slots are
emptied in increasing slot number into the output chute, first out at the
bottom.

**[PROOF] Every ordering is reachable and equiprobable.** The assignment
is an injective map from the n cards to the N slots. At step i there are
N − i empty slots, each chosen with probability 1/(N − i), so every
injective map has probability 1/(N(N−1)…(N−n+1)) = (N−n)!/N!. Each output
ordering π corresponds to exactly C(N, n) injective maps (choose which n
slots are used; the ordering then fixes which card goes to which of them).
Hence P(π) = C(N, n) · (N−n)!/N! = 1/n!. ∎ (For N = n this is Fisher–Yates
in its original "draw from the remaining set" form; Fisher & Yates 1938,
Durstenfeld 1964, Knuth TAOCP vol. 2 §3.4.2.)

Conditions the machine must satisfy:

* **(C1)** each draw is uniform on the currently empty set and independent
  of everything else (the RNG's job, §2.3);
* **(C2)** the card ends up in the chosen slot, and the unload delivers the
  slots in order (the mechanism's job, §2.4).

Corollaries: **[PROOF]** the law is uniform for *any* input order, so a
restart after a jam is as good as a fresh deck; one pass suffices; the two
unused slots may be anywhere.

## 2.3 Random numbers

Pipeline (`firmware/shuffler/rng.cpp`; bit-exact reference in
`simulation/rng_reference.py`; host test in `firmware/test_host`):

| Stage | What |
|---|---|
| Entropy | ESP32 hardware RNG with `bootloader_random_enable()` (SAR-ADC noise source) enabled during seeding; Espressif documents the output as true-random only while RF or this source is enabled. Plus timing jitter of sensor edges and button presses, ADC noise, boot and shuffle counters. |
| Health test | Repetition-count test on the raw 32-bit samples (4 identical in a row → abort with ERROR 5). Simplified NIST SP 800-90B §4.4. |
| Conditioning | key = SHA-256(64 B hardware ‖ 32 B jitter ‖ boot counter ‖ shuffle counter). |
| Generator | ChaCha20 keystream (RFC 8439); nonce = "SHF\x01" ‖ shuffle counter; block counter from 1. Reseeded per shuffle; no keystream reuse. |
| Sampling | `uniform(m)`: draw a 32-bit word x, accept iff x < 2³² − (2³² mod m), return x mod m. **[PROOF]** exact, no modulo bias; rejection probability ≤ 54/2³². (Lemire 2019 gives a faster variant, unnecessary here.) |
| Assignment | `slots_assign`: empty = [0..53]; for each card idx = uniform(len), slot = empty[idx], swap-remove. The swap changes the list order, not the uniformity of the choice. |

`test ref` on the ESP32 must print the same 52 slots as
`rng_reference.py --selftest`; `firmware/test_host` verifies the same
sequence and the predicted output order on the host.

## 2.4 What the mechanism can get wrong (condition C2)

| Fault | Cause | Effect on the realised assignment | Detection |
|---|---|---|---|
| **W1 neighbour slot, symmetric** | card enters the slot one above or below the target, equally likely (wheel index noise ±1 mm at the mouth, card tilt) | realised slot = intended ± 1 when that slot is empty | Beam E at the entry: after each feed the card must be seen in the target slot; if not, the firmware looks at both neighbours, finds the card and **corrects its occupancy map** (`VERIFY_AFTER_INSERT`), logging the direction |
| **W2 neighbour slot, biased** | entry plane trim wrong (always the same side) | realised = intended + 1 always when empty | As W1; the *direction statistics* of the corrections reveal it; `cal entry` trim |
| **W3 uncorrected W1/W2** | firmware not verifying | later card sent to an actually occupied slot: collision (jam) or deflection to a free neighbour | Only by the final count or a jam |
| **W4 double feed** | two cards through the gate | both cards in one slot, original order kept → adjacent in the output | Beam-B block-time heuristic; end count (52 loaded); the slot holds two cards, the exit pulls them together |
| **W5 card stuck / lost** | card stops in the slot mouth, or falls back | Stuck: beam S stays blocked. The nip nudges it, then a reverse pulse and a retry into the same slot (no effect on the law). If it is still stuck, ERROR 3, and the wheel refuses to turn while beam S is blocked. Lost: beam E is clear after the feed and the card is not in either neighbour, giving ERROR 8 | Beams S and E |
| **W6 eject failure** | card does not come out of a slot | beam X never blocks → retry, then ERROR 9; the deck is short | Sensor + count |
| **W7 missed feed / retry** | roller slips | same card into the same (still empty, still chosen) slot: **no effect on the law** [PROOF] | — |
| **W8 lost steps / wrong home** | stepper stall, index misread | An offset present for the whole load and unload changes nothing, because the order of the slots is preserved. Steps lost mid-load send later cards toward slots that may already hold a card | Before every feed the firmware checks with beam E that the target slot is empty. If it is not, it re-homes. If the slot is still occupied, it stops with ERROR 11 rather than guess. The machine also homes and scans before every shuffle |

**[PROOF] Symmetric, independent neighbour errors with map correction
preserve uniformity.** Let E be the set of truly empty slots when card i is
placed, s uniform on E, and the realised slot s' = s ± 1 with equal
probability p if that neighbour is in E, else s' = s. The kernel K(s → s')
on E is symmetric (K(a→b) = K(b→a)) and hence doubly stochastic, so s' is
uniform on E. With the map corrected, the next draw is uniform on the true
remaining set, and the argument of §2.2 applies to the realised assignment.
∎ Without correction (W3) the firmware's belief and the truth diverge and
uniformity is lost (see the table below). A biased kernel is not doubly
stochastic and produces a bias whether or not the map is corrected.

**[SIM] Effect sizes**, 200 000 shuffles per model (20 000 for riffles).
Columns: chi-square p of the 52 × 52 card-position table; largest cell in
σ; P(input bottom card ends at the bottom) (uniform 0.0192); pairwise
precedence pairs beyond 3σ (uniform ≈ 3.6 of 1326); mean original
successors directly above (uniform 0.981); Spearman z of input vs output
position; informed next-card guessing score (uniform 4.54).

| Model | pos-freq p | max σ | P(bot→bot) | pairs > 3σ | adjacency | Spearman z | guess |
|---|---|---|---|---|---|---|---|
| **Wheel, exact** | 0.72 | 3.4 | 0.0189 | 2 | 0.980 | 0.5 | 4.55 |
| W3 neighbour 5 % symmetric, **uncorrected** | 1.3 × 10⁻⁶ | 3.6 | 0.0189 | 48 | 1.005 | −6.4 | 4.57 |
| W3 neighbour 5 % biased, uncorrected | 2.6 × 10⁻⁴⁰ | 6.5 | 0.0181 | 308 | 0.980 | −17.3 | 4.53 |
| W3 neighbour 30 % symmetric, uncorrected | < 10⁻³⁰⁰ | 14.2 | 0.0191 | 613 | 1.136 | −39.2 | 4.81 |
| W1 neighbour 5 % symmetric, **corrected** (firmware default) | 0.16 | 3.6 | 0.0188 | 5 | 0.982 | 0.4 | 4.54 |
| W2 neighbour 5 % biased, corrected | 2.8 × 10⁻⁷ | 4.4 | 0.0179 | 34 | 0.935 | −5.5 | 4.60 |
| W2 neighbour 30 % biased, corrected | < 10⁻³⁰⁰ | 20.9 | 0.0133 | 1278 | 0.713 | −35.1 | 5.29 |
| W4 double feed 2 % (v1 model, same effect) | 5.8 × 10⁻⁷ | 5.9 | 0.0210 | 85 | **1.515** | 1.4 | 5.01 |
| 8-bin shelf shuffler, 1 pass | < 10⁻³⁰⁰ | 347 | 0.126 | 1326 | 6.39 | 403 | **17.1** |
| 8-bin shelf shuffler, 4 passes | 0.40 | 3.3 | 0.0196 | 3 | 0.989 | −0.6 | 4.55 |
| GSR hand riffle × 7 | 8.6 × 10⁻¹³ | 5.9 | 0.0242 | 151 | 1.197 | 7.5 | 4.64 |
| GSR hand riffle × 12 | 0.96 | 3.2 | 0.0197 | 5 | 0.981 | 1.3 | 4.54 |
| Two-hopper riffle machine × 7 | 1.6 × 10⁻⁹ | 7.2 | 0.0240 | 116 | 1.049 | 6.1 | 4.63 |

**[SIM] Exact total-variation distance for 6 cards** (wheel models with 8
slots, 10⁶ samples; the floor is a perfect source at the same sample size):

| Model | TV | floor |
|---|---|---|
| Wheel, exact | 0.0103 | 0.0110 |
| W3 neighbour 5 % symmetric, uncorrected | 0.0134 | 0.0109 |
| W3 neighbour 5 % biased, uncorrected | 0.0166 | 0.0111 |
| W1 neighbour 5 % symmetric, corrected | 0.0108 | 0.0110 |
| W2 neighbour 5 % biased, corrected | 0.0118 | 0.0109 |
| 8-bin shelf, 1 pass | 0.240 | 0.011 |

Reading: the wheel's only silent failure mode is a misplaced card the
firmware does not notice, which is exactly what beam E and the correction
routine are for. Every correction is logged with its direction, so a biased
entry plane shows up in the machine's own statistics long before it could
be seen in output statistics.

## 2.5 Riffle shuffles, for comparison

The Gilbert–Shannon–Reeds model (Gilbert 1955; Reeds 1981; Aldous &
Diaconis 1986) and its exact analysis by Bayer & Diaconis (1992, Theorem 1:
P(π) = C(2ᵏ + n − r, n)/2ᵏⁿ with r the number of rising sequences) give the
total-variation distance after k riffles of 52 cards
(`shuffle_sim.py --bd-table`):

| k | 1–4 | 5 | 6 | 7 | 8 | 9 | 10 | 11 | 12 |
|---|---|---|---|---|---|---|---|---|---|
| TV | 1.000 | 0.924 | 0.614 | **0.334** | 0.167 | 0.085 | 0.043 | 0.021 | 0.011 |

An N-bin shelf pass is the inverse of an N-riffle and k passes compose to
an Nᵏ-shuffle, so 8 bins × 4 passes ≈ 12 riffles. Diaconis, Fulman & Holmes
(2013) showed a real 10-shelf casino machine is exploitable after one pass.
Consumer two-hopper riffle machines are worse than GSR per pass (near-
perfect alternation, cut near 26). The wheel has no mixing-time question:
its ideal output is uniform after one pass, and its faults are the concrete
items in §2.4.

## 2.6 A second exact architecture (kept for reference): two wells

If cards are diverted to two insertion wells A and B, each performing
uniform random-gap insertion, and stack A is placed on stack B at the end,
the result is exactly uniform whenever the label vector L ∈ {A,B}ⁿ is
*exchangeable* (P(L) depends only on the number of A's), e.g. i.i.d. coin
flips of any bias or a uniformly random 26/26 split. **[PROOF]** For a
target π and each k, the event "top k of π = the A cards in π's order" has
probability f(k)/(k!(n−k)!); summing over k gives
(1/n!) Σₖ f(k) C(n, k) = (1/n!) Σ_L P(L) = 1/n!. ∎ This was the alternative
to the wheel; it is slower and needs the user to combine two stacks.

## 2.7 What the tests can and cannot establish

* B shuffles resolve deviations of about 1/√B per cell; 200 000 shuffles
  see cell probabilities to ±0.0005. No finite test proves uniformity over
  10⁶⁸ outcomes.
* The argument for this machine is therefore layered: (1) the algorithm is
  uniform **[PROOF]**; (2) the RNG and sampler are checked bit-for-bit
  against the reference and statistically on the chip; (3) every insertion
  is verified by a sensor and every deviation is logged with its direction,
  so the residual physical error is *measured*, not assumed; (4) the
  predicted-vs-actual test checks the whole chain including the unload.

## 2.8 Validation plan (strongest evidence first)

1. **RNG bit-exact** — `test ref` = `rng_reference.py --selftest` ★
2. **RNG statistics on the chip** — `test rng 100000` →
   `analyze_physical.py --gaps` (slot sequences; every statistic in the
   uniform ranges) ★
3. **Entropy health** — `test raw 1000000` → `ent` / NIST STS ≈ 8.0 bits/byte ★
4. **Insertion accuracy from the machine's own log** — after every shuffle
   `last` prints intended and realised slots. Over 20 shuffles (1040
   insertions) the acceptance target **[EST]** is ≤ 1 % corrections with no
   directional excess beyond the binomial test (p > 0.05), 0 lost cards,
   0 double-feed suspects. `analyze_physical.py --log` tallies this. ★
5. **Predicted-vs-actual** — `test fixed <seed>`, press the button, then
   read the output deck (`analyze_physical.py --compare`). Every
   discrepancy is a mechanical error not caught by the sensors (eject
   order, unnoticed misplacement, double card). 20 decks. ★
6. **Output statistics on physical shuffles** — 200–500 decks entered by
   hand; only gross faults are visible at this size; sanity check.
7. **Different starting orders** — sorted, reversed, previously shuffled:
   5 decks each of step 5. Input independence is proved for the algorithm;
   this checks the mechanics do not depend on order (new vs worn decks).
8. **Fault injection** — misalign `cal entry` by +1.5° and confirm the
   correction log shows a directional excess; set the gate to 0.8 mm and
   confirm the double-feed warning.

**Approximation target [EST].** Under the step-4 acceptance criteria, with
symmetric residual errors and map correction, the output law is exactly
uniform by §2.4; the residual risk is an undetected directional bias at
the 1 % level, which corresponds to a total-variation distance of order
0.01 (comparable to 12 hand riffles). To be validated, not claimed.

## References

* R. A. Fisher, F. Yates, *Statistical Tables*, 1938, example 12.
* R. Durstenfeld, "Algorithm 235: Random permutation", *CACM* 7(7), 1964.
* D. E. Knuth, *TAOCP* vol. 2, §3.4.2.
* E. N. Gilbert, "Theory of shuffling", Bell Labs memo, 1955.
* D. Aldous, P. Diaconis, "Shuffling cards and stopping times", *Amer.
  Math. Monthly* 93(5), 1986.
* D. Bayer, P. Diaconis, "Trailing the dovetail shuffle to its lair",
  *Ann. Appl. Probab.* 2(2), 1992.
* P. Diaconis, J. Fulman, S. Holmes, "Analysis of casino shelf shuffling
  machines", *Ann. Appl. Probab.* 23(4), 2013.
* L. N. Trefethen, L. M. Trefethen, "How many shuffles to randomize a deck
  of cards?", *Proc. R. Soc. A* 456, 2000.
* D. Lemire, "Fast random integer generation in an interval", *ACM TOMACS*
  29(1), 2019.
* RFC 8439 (ChaCha20); Espressif ESP-IDF "Random Number Generation";
  NIST SP 800-90B §4.4.

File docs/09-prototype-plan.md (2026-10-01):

# 9. Staged prototype plan

The wheel's risks, in order: single-card feeding, card entry into a slot,
card slide-out at the exit, and unload throughput. Each stage tests one
before the next print job.

## Stage 0 — electronics on the bench (1 evening, ≈ $30)

ESP32, two DRV8833, three N20 and the IR pairs on a breadboard.
Flash; `beams`, `feed` (motors spinning free), `test ref`. Purpose: the
toolchain and sensors work; `test ref` matches the Python reference.

## Stage 1 — feeder module (1 weekend, ≈ $45 cumulative)

Print feeder_deck, gate_block, roller_feed, one roller_nip, the two feeder
brackets, one idler_arm, two idler_wheels, lid. Assemble steps
1–12. Clamp the deck at 50° with a box under the tip.

Tests: 100 single feeds; gate window (expect 0.40–0.50 mm for 0.30 mm
cards); thin/thick/worn decks; card exit speed from the B-block time;
confirm a card leaving the nip at 50° slides ≥ 20 mm on a PETG surface.
Exit criterion: 300 single feeds in a row across three deck types.
Fallback: cork retard strip on the gate lip.

## Stage 2 — wheel + towers, hand feeding (1 weekend, ≈ $75 cumulative)

Print wheel, both towers, shroud_A/B, shutter, index_bracket; buy the stepper, driver, rod, bearings, coupler, servo. Assemble
steps 13–22 on the joined base boxes (print them now or use a plywood
board with the tower foot holes).

Tests: homing repeatability (10 homes, `entry 0`, mark the rim: spread
< 0.5 mm); `entry k` for 10 random k then a hand-pushed card: beam E
blocked and beam S clear 50/50; the beam S interlock refuses `jog` with a
card half in the mouth; rotate the loaded wheel 20 revolutions each way: no card
lost, none touching the shroud in the upper half; the shutter opens and a
card at `exit k` slides out into a hand-held box 50/50. Measure the index
time for 90° (target ≤ 0.3 s) and the stall margin (increase
`WHEEL_ACC_DPS2` from 5000 until it skips, then back off 30 %).
Exit criterion: 50/50 entries, 50/50 slide-outs, no lost cards.

## Stage 3 — feeder on the wheel (1 evening)

Mount the feeder deck (step 23). `feed` with `entry k`: 100 cards, 0
corrections, 0 lost; `scan` confirms the map. Tune `cal entry`.
Exit criterion: 200 feeds, ≤ 1 correction, all in the intended slot after
correction.

## Stage 4 — exit module and full cycle (1 weekend, ≈ $115 cumulative)

Print chute, second idler_arm, wheels; buy the rest. Steps 25–37. 20
fixed-seed shuffles with predicted-vs-actual comparison; tune timeouts,
PWMs, `cal exit`. Record the cycle time.
Exit criterion: section E of `08-verification-checklist.md`.

## Stage 5 — endurance and statistics

200 shuffles over weeks of play; `cal show` statistics; output statistics;
card wear inspection; battery life measurement.

## Fallbacks

| Failure | Fallback within this design |
|---|---|
| Cards stop in the slot mouth | polish the fin faces (600 grit); raise `cal pwm nipe`; steepen `entry_slot_ang` to 55° (reprint feeder arms via params) |
| Cards catch on the shroud | shim the shroud outward 0.5 mm; felt strip inside the shroud; smaller `r_shroud_in` clearance not needed |
| Cards do not slide out at the exit | steepen `exit_slot_ang` to 210°; shorten the shutter/nip distance; raise `cal pwm nipx` |
| Wheel too heavy for the index time | bigger fin windows in params; 0.8 A Vref; NEMA 17 high-torque (60 N·cm) |
| Double feeds | cork retard on the gate; lighter lid |
| Index unreliable | bare TCST2103 interrupter in the index bracket instead of the module |

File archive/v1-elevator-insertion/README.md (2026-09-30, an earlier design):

# Open card shuffler — single-card random-gap insertion, 3D-printed, battery powered

A one-button shuffler for one 52–54 card poker deck. Cards are fed one at a
time from a hopper into a vertical well whose stack rests on an elevator;
before each card, two thin blades open a gap at a uniformly random position
and the card is pushed in. That is the inside-out Fisher–Yates algorithm
executed physically: every ordering of the deck is equally likely when the
mechanism does what it is told, and the design is arranged so that the ways
it can fail to do so are detectable.

**Status: complete design, unbuilt.** Nothing in this repository has been
printed, wired or tested on hardware. Every performance number is an
estimate and is labelled as such. Do not describe this machine as proven or
as guaranteed uniformly random; the validation plan says how to earn those
words.

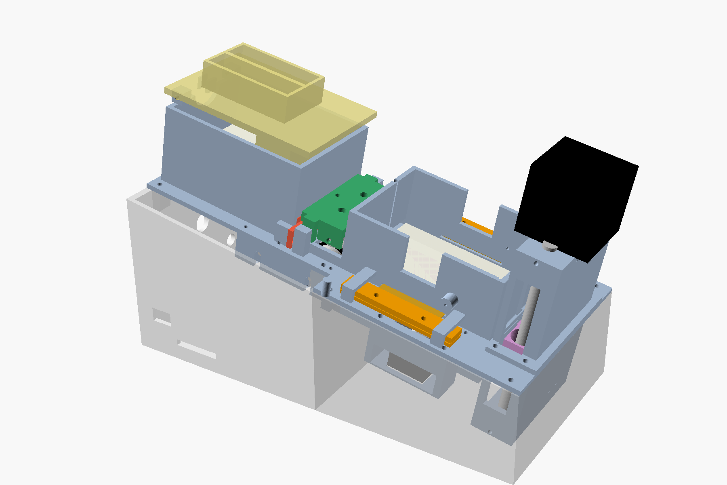
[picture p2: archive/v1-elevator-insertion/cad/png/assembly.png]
assembly


## What is here

| Deliverable | Where |
|---|---|
| Mechanism comparison and selection (riffle, bin routing, carousel, gap insertion) | `docs/01-mechanism-selection.md` |
| Mathematics: uniformity proof, RNG pipeline, fault analysis, riffle theory, validation plan | `docs/02-mathematics.md` |
| Simulation code and results | `simulation/shuffle_sim.py`, `simulation/results/` |
| Bit-exact RNG reference and physical-test analysis | `simulation/rng_reference.py`, `simulation/analyze_physical.py` |
| Parametric CAD (OpenSCAD), 19 printable STLs, assembly / exploded / section views | `cad/params.scad`, `cad/shuffler.scad`, `cad/stl/`, `cad/png/` |
| Mechanical design document (dimensions, tolerances, adjustments, card protection) | `docs/03-mechanical-design.md`, `cad/print-settings.md` |
| Electronics, battery, power budget, pin table | `docs/04-electronics.md`, `electronics/wiring-diagram.svg` |
| Bill of materials | `docs/05-bom.md`, `electronics/bom.csv` |
| Firmware (ESP32, Arduino framework) with host-tested RNG core | `firmware/` |
| Assembly instructions, calibration, first-use checks | `docs/06-assembly.md` |
| Operation, maintenance, troubleshooting | `docs/07-operation-maintenance-troubleshooting.md` |
| Verification checklist | `docs/08-verification-checklist.md` |
| Staged prototype plan | `docs/09-prototype-plan.md` |
| What could not be produced here, and open unknowns | `docs/10-deliverables-and-gaps.md` |
| Diagrams | `docs/img/mechanism-section.svg`, `docs/img/insertion-sequence.svg`, `docs/img/firmware-states.svg` |

## Headline numbers (all estimates unless stated)

| | |
|---|---|
| Parts cost, excluding printing | ≈ $121 new; ≈ $104 with a normal parts drawer; ≈ $95 minimum configuration |
| Cycle time, 52 cards | 70–80 s first build; ~45–50 s tuned. **The 30 s target is not reachable with this architecture.** |
| Randomness | Exact uniform in the ideal model (proof in §2.2); symmetric ±1 blade errors provably harmless; systematic errors and silent faults are measurable with the predicted-vs-actual test |
| Size | 261 × 126 mm footprint, ≈ 160 mm tall |
| Battery | 3S Li-ion 2200 mAh with BMS; ≈ 0.085 Wh per shuffle → about 200 shuffles or 3 game evenings per charge |
| Cards | 52–54, thickness 0.22–0.42 mm (gate adjustable) |

## Quick start for a builder

1. Read `docs/01` and `docs/03` to understand the mechanism.
2. Follow `docs/09-prototype-plan.md`: build and test the feeder alone
   first, then the well, then integrate.
3. Print with `cad/print-settings.md`; buy from `docs/05-bom.md`; wire from
   `electronics/wiring-diagram.svg`; flash `firmware/`; calibrate with
   `docs/06-assembly.md` §6.7; verify with `docs/08`.

## Reproducing the analysis

```
pip install numpy scipy
python3 simulation/shuffle_sim.py --quick        # ~1 min
python3 simulation/rng_reference.py --selftest
cd firmware/test_host && make run                # host test of the firmware RNG core
cd cad && ./render.sh                            # needs OpenSCAD 2021.01 and xvfb-run for PNGs
```

## Licence

Everything here is released under CC BY 4.0 (documentation, CAD) and the
MIT licence (code). Attribution appreciated; no warranty of any kind — see
the safety notes in `docs/07`.

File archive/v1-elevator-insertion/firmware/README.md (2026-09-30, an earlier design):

# Firmware (ESP32 DevKitC, Arduino framework)

```
shuffler/
  shuffler.ino     main state machine, shuffle procedure, button, low-battery behaviour
  config.h         pins, mechanical constants, defaults, calibration record
  platform.*       core 2.x / 3.x shims (LEDC, NeoPixel, hardware RNG with the ADC entropy source)
  hardware.*       stepper, servos, DRV8833 motors, IR beams, endstop, button, battery, LED, buzzer
  motion.*         elevator (home, move, find beam S) and feeder (probe, feed one card, reverse pulse)
  rng.*            entropy health test, SHA-256 conditioning, ChaCha20 DRBG, rejection sampling
  sha256.*  chacha20.*   portable primitives
  shuffle_core.*   gap drawing + permutation prediction (pure, host-tested)
  storage.*        calibration in NVS
  cli.cpp          serial console (115200): calibration, tests, RNG dumps
test_host/         `make run` — host unit test of the RNG/algorithm core against the Python reference
platformio.ini     `pio run -e esp32dev`
```

Build with PlatformIO (`pio run -e esp32dev -t upload`) or the Arduino IDE
(board "ESP32 Dev Module"; open `shuffler/shuffler.ino`; no external
libraries are needed — the NeoPixel is driven by the core's RMT helper).
Serial console at 115200 baud; type `help`.

## Randomness pipeline

See `docs/02-mathematics.md` §2.3. In short: `bootloader_random_enable()` →
64 bytes of hardware random → health test → SHA-256 with a jitter pool
(sensor edge timestamps, button timing, ADC noise) and counters → ChaCha20
keystream → rejection-sampled gap indices. `test ref` must print the same
52 gaps as `simulation/rng_reference.py --selftest`.

## Bring-up order (see docs/06-assembly.md §6.9 for details)

1. `bat` → set `cal vbat <multimeter volts>`.
2. `beams` with nothing in the machine; `cal beams`.
3. `home`; `z 0`; `z 10`; `cal home` (empty well).
4. `blades in` / `blades out`; adjust `cal servo …` until the blades protrude 7 mm / sit 1 mm inside the wall.
5. `probe`, `feed` with a deck loaded; adjust `cal pwm …` and the gate.
6. `cal knifetest 10` with a deck in the well; adjust `cal knife ±0.025`.
7. `test fixed 1`, press the button, compare with `simulation/analyze_physical.py --compare`.

## Status of this code

Written for this design; the platform-independent core (`rng`, `sha256`,
`chacha20`, `shuffle_core`) is unit-tested on the host and matches the
Python reference bit for bit. The hardware modules follow the Arduino-ESP32
APIs of both core 2.x and 3.x but **have not been compiled for the ESP32**:
the authoring environment could not download the Espressif toolchain (see
`docs/10-deliverables-and-gaps.md`). Expect first-compile fixes, and expect
to tune every timeout and PWM value on real hardware.

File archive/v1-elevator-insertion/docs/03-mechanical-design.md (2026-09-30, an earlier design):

# 3. Mechanical design and printable parts

Source of truth: `cad/params.scad` (every dimension) and `cad/shuffler.scad`
(every part, the assembly, exploded and section views). STL files rendered
from them are in `cad/stl/`, views in `cad/png/`. `cad/render.sh` regenerates
everything with OpenSCAD 2021.01.

| View | File |
|---|---|
| Assembly | `cad/png/assembly.png` |
| Exploded assembly | `cad/png/exploded.png` |
| Section at the centreline | `cad/png/section.png`, annotated: `docs/img/mechanism-section.svg` |
| Feeder module exploded | `cad/png/feeder_exploded.png` |
| Well module exploded | `cad/png/well_exploded.png` |
| Insertion sequence | `docs/img/insertion-sequence.svg` |

## 3.1 Coordinate frame and overall layout

The "card frame" has X along the card travel (hopper → well), Y across the
card, Z normal to the cards; the card path plane is Z = 0. The whole card
frame is tilted 10° (well end low) and sits on two wedge-shaped skirts whose
bottoms are flat on the table.

| | mm |
|---|---|
| Footprint (skirts) | 261 × 126 |
| Height, hopper end (lid closed) | ≈ 155 |
| Height, column end (stepper on top) | ≈ 160 |
| Card path plane above the table at X = 0 | 90 |
| Mass (printed parts ≈ 650 g + hardware) | ≈ 1.4 kg [EST] |

Two modules bolt together at a vertical flange at X = 47 mm:

* **Feeder module** (X −87 … +47): hopper, gate, feed and transport rollers,
  idler arm, gate beam, lid. Electronics and battery in the front skirt below.
* **Well module** (X 47 … 176): well, blade bars, servos, elevator column.

## 3.2 Card path geometry

| Feature | X (mm) | Z (mm) | Note |
|---|---|---|---|
| Hopper interior | −81 … +10 | 0 … 50 | 65.0 wide (card 63.5 + 1.5), 91.0 long (card 88.9 + 2.1) |
| Feed roller axis | −4 | −12.8 | Ø27 crown, protrudes 0.7 above the floor |
| Gate lip (inner face of gate wall) | 10 | gap 0.30–0.60 | set by feeler gauge, nominal 0.45 |
| Gate beam B (vertical) | 19 | — | emitter in plate, phototransistor in idler arm |
| Transport roller axis | 32 | −13.0 | Ø27 crown, protrudes 0.5 |
| Idler wheels | 32 | axle 6.85 | Ø12 wheels with 9×2 O-rings, two at Y = ±20 |
| Well front wall (outer/inner face) | 47 / 50 | | entry slot Z −1.0 … +3.5 |
| Well slot beam W (vertical) | 48.5 | through the slot | Y = 12 |
| Well interior | 50 … 141 | −30 … +38 | 65 wide; felt pad 1.5 mm on the back wall |
| Blade mid-plane | 75.5 … 115.5 (blade width) | +2.5 | enters 7 mm from each side wall |
| Stack-top beam S (horizontal) | 117.5 | +14 | 1.6 mm apertures in both side walls |
| Platform | 52 … 138 | travel −25 … +22 | 45 wide (blades pass beside it), 4 thick |
| Lead screw axis / rods | 158 | | rods at Y = ±22, 8 × 120 mm |

Why these numbers:

* **Coasting.** The transport nip releases a card when its trailing edge
  passes X = 32; the leading edge is then at X ≈ 121, 18.5 mm short of the
  pad at 139.5. At 10° tilt and 0.2–0.25 m/s the card coasts 17–26 mm
  (μ ≈ 0.3 card-on-card) — enough, with margin, to seat on the felt pad
  every time. On a level path it would stop short.
* **Gap height.** Lower stack top at Z = −0.5, blade underside at +2.25:
  the incoming card (on the Z = 0 plane) has 0.5 mm below and 1.9 mm above.
* **Platform width 45.** Cards overhang the platform by 9.25 mm per side; the
  blades enter 7 mm, so they can slide under the bottom card (gap index 0)
  without touching the platform.
* **Slot height 4.5 mm (−1.0 … +3.5).** Tall enough for a curled card,
  short enough that no card of the lower stack (top at −0.5) can escape.

## 3.3 Feeder: single-card separation

The deck sits face down on the hopper floor. The bottom card rests on the
feed roller's three nitrile O-rings (μ ≈ 0.7 on card stock) and on the
floor. The 10° tilt slides the deck against the gate wall. The gate block's
lower edge is set 1.3–1.5 card thicknesses above the floor with a feeler
gauge; only the bottom card fits under it, and the block's rounded lip
holds back the second card. This is the separation method of every desktop
card dealer and most printers ("gate" or "retard lip").

Normal force on the bottom card = deck weight (≤ 90 g) + lid pressure. The
lid's hanging boss (with a felt pad) reaches the floor, so pressure does not
vanish as the deck empties; two AA cells in the lid's troughs give ≈ 70 g at
the boss through the lever ratio (lid CG 45 mm from the hinge, boss 70 mm).
Add washers to the troughs if the last cards feed unreliably; remove ballast
if cards feed double (too much force can push the second card under the
lip on very thin decks).

Feed force ≈ 0.7 × (0.7 … 1.6 N) ≈ 0.5 … 1.1 N. Card-to-card drag on the
second card ≈ 0.3 × N, which is what the lip resists.

After the gate, the card enters the transport nip: transport roller
(O-rings) below, two spring-loaded idler wheels above (two pen springs,
≈ 2 N total). Both rollers run from separate N20 motors so the feed roller
can stop as soon as beam B clears (trailing edge past the gate) while the
transport roller finishes the card; the next card is then already
"pre-staged" 10 mm past the gate, singulated, waiting.

**Thickness range.** The gate is adjustable from 0.30 to 0.60 mm (slots
8 mm long give more than needed). Standard cards 0.25–0.35 mm → set
0.42–0.45. Thick custom decks 0.40 mm → set 0.55. The rule is
t_max < gap < 2 × t_min.

## 3.4 Well, blades, elevator

* **Blades.** Two 40 × 22 × 0.5 mm brass blades (K&S sheet) or two pairs of
  0.45–0.55 mm feeler-gauge blades, each sandwiched between a printed lower
  and upper bar half (M3 × 10 × 2). Entry edge: file a symmetric bevel
  about 1.5 mm long on both faces (tip ≈ 0.1 mm), round the two corners,
  polish to 600 grit. The symmetric bevel makes the tip self-centre into
  the nearest card boundary when the elevator is up to ±0.15 mm off.
* **Bars.** 70 × 12 × 6 mm, sliding in two printed guide loops per side,
  8 mm travel. Driven by an MG90S below the plate through a 2 mm pin on the
  horn at r = 8 mm (±30° = 8 mm). A rubber band or light spring between the
  bar's hook hole and the post on the plate returns the bar outward when
  the servo is unpowered (blades out = safe default).
* **Well walls** are printed in two parts: the upper walls are part of the
  well deck (plate on the bed, walls up); the lower sleeve (Z −30 … −3)
  screws to the plate's underside. Both have the 7 mm arm slot in the back
  wall and the felt-pad recess.
* **Elevator.** T8×8 4-start lead screw (8 mm per turn; 400 µsteps/mm at
  1/16), flanged brass nut on the carriage's rear beam, two 8 mm rods with
  LM8UU bearings 44 mm apart, NEMA 17 on top of the column driving through
  a flexible coupler; the screw's lower end runs free in a clearance hole
  (Ender-3 style). The carriage arm passes through the 7 mm slot in the
  well's back wall; the platform screws to the arm's spine from above.
  Resolution 0.0025 mm; positioning repeatability is limited by the print,
  not the drive.
* **Endstop** at the column bottom, tripped by the rear beam at Z ≈ −26.
  The Z origin is then set by the beam-S auto-calibration (§3.7).
* **Stack-top measurement.** With blades out, the platform rises slowly
  until beam S blocks; the platform top is defined to be at Z = 14.0 at
  that instant (empty well, calibration) or the stack top is (with cards).
  Because the same threshold crossing is used for both, the beam's exact
  height and threshold cancel out of the thickness estimate.

## 3.5 Printed parts list

All parts print without supports in the orientation the STL is exported in
(the selector in `cad/shuffler.scad` applies the rotation; every STL rests on
Z = 0).

| # | Part | Qty | Size (mm) | Material | Notes |
|---|---|---|---|---|---|
| 1 | feeder_deck | 1 | 134 × 90 × 83 | PETG/PLA | hopper + plate + rails; plate on the bed |
| 2 | gate_block | 1 | 81 × 15.5 × 6 | PETG | flange face down; round the lip after printing |
| 3 | roller | 2 | Ø24 × 72 | PLA | axis vertical, stub up; 0.15 mm layers |
| 4 | motor_bracket | 1 | 68 × 27 × 19 | PETG | mating face on the bed |
| 5 | motor_retainer | 2 | 22 × 12 × 2.5 | any | |
| 6 | bushing_bracket | 1 | 68 × 7 × 19 | PETG | |
| 7 | idler_arm | 1 | 28 × 69 × 16 | PETG | printed upside down |
| 8 | idler_wheel | 2 | Ø12 × 6 | PLA | |
| 9 | lid | 1 | 103 × 71 × 79 | PLA | printed upside down (troughs bridge 15 mm) |
| 10 | well_deck | 1 | 129 × 131 × 63 | PETG | plate on the bed; guide loops bridge 22 mm |
| 11 | well_sleeve | 1 | 99 × 82 × 27 | PETG | |
| 12 | knife_bar_lower | 2 | 70 × 12 × 2.25 | PETG | 0.15 mm layers (blade seat) |
| 13 | knife_bar_upper | 2 | 70 × 12 × 3.25 | PETG | |
| 14 | servo_bracket | 2 | 48 × 18 × 29 | PETG | |
| 15 | column | 1 | 30 × 90 × 119 | PETG | upright; top plate bridges 66 mm — add a 0.4 mm sacrificial layer or enable supports for that bridge only |
| 16 | carriage | 1 | 24 × 62 × 74 | PETG | on its rear face |
| 17 | platform | 1 | 86 × 45 × 4 | PLA | flat; sand the top smooth |
| 18 | skirt_front | 1 | 134 × 126 × 102 | PLA | open top up |
| 19 | skirt_rear | 1 | 128 × 126 × 79 | PLA | open top up |

Print settings: 0.2 mm layers (0.15 for rollers and bar halves), 0.4 mm
nozzle, 3 perimeters, 4 top/bottom layers, 25 % infill (40 % for the
carriage and column), PETG at 235–245 °C for the parts that see load or
warmth (decks, column, carriage, brackets), PLA is acceptable everywhere for
a first prototype. Print the two decks with a brim.

## 3.6 Tolerances, clearances, adjustment points

| Fit | Nominal | Adjustment |
|---|---|---|
| Card in hopper / well width | 65.0 (card 63.5) | none needed; if cards bind, scale the print 100.3 % in Y |
| Gate gap | 0.45 | slotted clamp, feeler gauge (the critical adjustment) |
| Blade height vs boundary | ±0.15 | firmware `cal knife` (±0.025 mm steps), plus the print's ±0.15; `cal knifetest` to inspect |
| Bar in guide loop | 12.0 in 12.3 (Y), 6.0 in 6.4 (Z) | sand the bar if tight; the bar must slide freely under its own return spring |
| Blade slot in wall | 1.6 tall for a 0.5 blade | none (the bar defines the height) |
| LM8UU in carriage | 15.0 in 15.2 | press fit; drop of CA if loose |
| T8 nut flange recess | 22.5 | 4 × M3 |
| N20 in bracket pocket | 12.4 × 10.4 | retainer plate |
| Servo horn pin in bar slot | 2.0 in 2.8 (Y) × 4.8 (X) | the slot's X length absorbs the horn arc |
| Idler pressure | 2 pen springs | swap springs or add a washer under them |
| Idler axle height | 6.85 → 0.15 interference with the roller crown | none (arm floats) |
| Stack-top beam | 1.6 mm apertures | firmware threshold auto-set (`cal beams`) |
| Card entry slot | 4.5 tall | none |
| Skirt / deck alignment | 4 × M3 per module into bosses | oversize holes in the plates |

Print variation: the design uses ±0.3 mm sliding clearances everywhere a
printed part slides on a printed part, and every dimension that matters for
randomness (blade height, stack height) is calibrated by sensor, not trusted
from the print.

## 3.7 Calibration features designed into the parts

1. **Beam S defines Z.** `cal home` raises the empty platform until beam S
   blocks and declares that height Z = 14.0. The blade slot is 11.5 mm below
   the beam in the same print, so the blade plane is at 2.5 ± 0.15; the
   residual is trimmed with `cal knife`.
2. **`cal knifetest k`** puts gap k of a loaded stack at the blades and
   extends them so you can see (through the finger notches) whether the
   blade entered a boundary cleanly.
3. **Gate by feeler gauge**: no printed dimension is trusted for the gap.
4. **Beam thresholds** are auto-set from the clear readings.

## 3.8 Card protection

| Risk | Design response |
|---|---|
| Scratches | Rolling contact only (O-rings, idler O-rings); felt pad on the back wall; felt under the lid boss; all card-contact edges rounded (gate lip R1, slot edges chamfered); blades polished with rounded corners |
| Bent corners | Straight path; the well interior is only 1.5 mm wider than the card so a card cannot skew far enough to catch a corner; 10° tilt seats cards square on the pad; jam detection stops the motors within one poll (~1 ms) of a timeout |
| Excessive pressure | Idler ≈ 2 N; lid ≈ 0.7 N; blades carry the upper stack on 2 × 7 × 40 mm — pressure < 1 kPa |
| Exposed faces | Deck loaded face down under a lid; cards travel face down; the well is enclosed except the top (only the top card's back is visible) |
| Double feed | Gate lip at 1.3–1.5 t; lid pressure moderate; beam-B block-time heuristic; end-of-shuffle count check |
| Inconsistent feed | Positive lid pressure to the last card; pre-staged next card; sensor-timed feed (not open-loop timing); retries with reverse pulse |
| Print variation | Calibrated by sensors (§3.7); adjustable gate; sliding clearances 0.3 mm |

## 3.9 Things a builder may want to change

* `TILT` (10°): more tilt = more coasting margin, taller machine.
* `roller_d` and O-ring size: any crown Ø24–28 works if `feed_z`/`trans_z`
  follow (they do, automatically).
* `plat_w`: narrower gives more blade clearance but less card support.
* `col_top_z`, `rod_len`: for a pancake stepper or different rods.
* `n_cards_max`: 54 by default; the well and travel allow up to about 60.

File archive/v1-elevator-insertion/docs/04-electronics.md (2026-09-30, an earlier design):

# 4. Electronics and battery power

Wiring diagram: `electronics/wiring-diagram.svg`. Bill of materials:
`05-bom.md` / `electronics/bom.csv`. Firmware: `firmware/shuffler/`.

All current and energy figures below are **estimates [EST]** from datasheet
values; none has been measured on a built unit.

## 4.1 Architecture

```
 3S Li-ion pack (BMS) ─ fuse 3 A ─ switch ─┬─ VBAT (9.0–12.6 V) ─► TMC2208 ─► NEMA 17 (elevator)
 charge jack ── to pack terminals           │                    └► 100k/33k divider ─► ADC (GPIO39)
                                            └─ buck 5.0 V / 3 A ─┬─► ESP32 DevKitC (VIN)
                                                                 ├─► DRV8833 (VM) ─► 2 × N20 (feed, transport)
                                                                 ├─► 2 × MG90S servo (blades)
                                                                 ├─► 3 × IR LED (switched by NPN)
                                                                 └─► WS2812B pixel
 Sensors (3V3): 3 phototransistors ─► ADC GPIO34/35/36, endstop ─► GPIO32, button ─► GPIO21
```

## 4.2 Component choices

| Function | Part | Why | Alternatives |
|---|---|---|---|
| Controller | ESP32 DevKitC V4 (WROOM-32, 30 pins) | Hardware RNG, plenty of GPIO, LEDC PWM for servos/motors, ADC1 for sensors, USB serial for test dumps, Arduino support | ESP32-S3 DevKitC (same code, pin remap); Raspberry Pi Pico (needs different RNG source and PWM code) |
| Stepper driver | TMC2208 stepstick (standalone mode, 1/16 µstep) | Quiet, 4.75–36 V input so it also works from 2S packs, stall-free at 0.65 A | A4988 (needs ≥ 8 V, noisier), DRV8825 |
| Elevator motor | NEMA 17, 1.5–1.7 A class (17HS4401) or 1.0 A 23 mm (17HS4023) | Ubiquitous 3D-printer part; run at 0.65 A RMS it has far more torque than the 150 g load needs | Integrated lead-screw NEMA 17 (no coupler) |
| DC motor driver | DRV8833 dual H-bridge module | Two channels, 1.5 A peak each, works at 5 V | TB6612FNG |
| Feed / transport motors | N20 6 V 300 rpm micro gearmotors ×2 | Cheap, compact, D-shaft; ~0.25 m/s card speed on Ø27 rollers at ~70 % PWM | N20 200–500 rpm (adjust PWM) |
| Blade servos | MG90S metal gear ×2 | 1.8 kg·cm, 0.1 s/60°, cheap | SG90 (plastic gears; acceptable) |
| Card sensors | 3 mm 940 nm IR LED + phototransistor pairs ×3 | Vertical beams detect any card regardless of back colour; cheap | 3 mm slotted photo-interrupter modules where geometry allows |
| Endstop | KW11/KW12 lever microswitch, NC contact | Wire-break safe | Optical endstop module |
| Battery | 3S Li-ion 11.1 V 2200–2600 mAh pack **with built-in BMS** (18650 ×3) | Commercially assembled and protected; 12.6 V charger adapters are cheap; gives the stepper full speed | See §4.6 for the USB-C option |
| Charger | 12.6 V 1 A CC/CV Li-ion charger with 5.5×2.1 barrel plug | Matches 3S packs; ~2.5 h charge | 12.6 V 2 A |
| 5 V rail | MP1584 or LM2596 buck module set to 5.0 V, ≥ 3 A | Servos and motors need a stiff 5 V | — |
| Indicators | WS2812B pixel + passive piezo | One RGB LED shows every state; beeps for done/jam/battery | 3 discrete LEDs |

## 4.3 ESP32 pin assignment

Strapping pins (0, 2, 12, 15) are avoided. GPIO 34–39 are input-only with no
internal pull-ups (external 10 kΩ pull-downs on the phototransistor
outputs). ADC2 pins are not used for analog input.

| GPIO | Name | Direction | Connected to |
|---|---|---|---|
| 25 | STEP | out | TMC2208 STEP |
| 26 | DIR | out | TMC2208 DIR |
| 27 | STEP_EN | out (active low) | TMC2208 EN |
| 16 | FEED_IN1 | out (PWM) | DRV8833 AIN1 |
| 17 | FEED_IN2 | out | DRV8833 AIN2 |
| 4 | TRANS_IN1 | out (PWM) | DRV8833 BIN1 |
| 5 | TRANS_IN2 | out | DRV8833 BIN2 |
| 23 | DRV_SLEEP | out | DRV8833 nSLEEP (held low until init) |
| 18 | SERVO_L | out (50 Hz PWM) | left MG90S signal |
| 19 | SERVO_R | out (50 Hz PWM) | right MG90S signal |
| 13 | IR_LED_EN | out | NPN base via 1 kΩ (switches all 3 IR LEDs) |
| 14 | PIXEL | out | WS2812B DIN via 330 Ω |
| 33 | BUZZER | out (LEDC tone) | piezo via 100 Ω |
| 34 | BEAM_B | ADC1 | gate beam phototransistor emitter (10 kΩ to GND) |
| 35 | BEAM_W | ADC1 | well-slot beam phototransistor |
| 36 | BEAM_S | ADC1 | stack-top beam phototransistor |
| 39 | VBAT | ADC1 | 100 kΩ / 33 kΩ divider, 100 nF |
| 32 | ENDSTOP | in, pull-up | microswitch NC to GND |
| 21 | BUTTON | in, pull-up | start button to GND |
| 22 | DECK_SENSE | in (optional) | TCRT5000 module DO |

## 4.4 Power budget [EST]

Assumptions: 3S pack at 11.1 V nominal; buck efficiency 85 %; stepper driver
disabled between moves (lead screw is self-locking); one shuffle = 52 cards
in 75 s.

| Load | Condition | Current | Power | Duty during shuffle | Average |
|---|---|---|---|---|---|
| ESP32 DevKitC (Wi-Fi off) | always | 80 mA @ 5 V | 0.40 W | 100 % | 0.40 W |
| IR LEDs (3 × 20 mA, 50 % modulated) | polling | 30 mA @ 5 V | 0.15 W | 100 % | 0.15 W |
| WS2812B | on | 20 mA @ 5 V | 0.10 W | 100 % | 0.10 W |
| NEMA 17 via TMC2208, 0.65 A RMS | moving | ≈0.45 A @ 11.1 V | 5.0 W | 40 % | 2.0 W |
| 2 × MG90S | moving 0.2 s ×2 per card, holding otherwise while extended | 0.3 A / 0.1 A @ 5 V | 1.5 / 0.5 W | 30 % / 40 % | 0.65 W |
| 2 × N20 (0.15 A each running) | feeding 0.5 s per card | 0.3 A @ 5 V | 1.5 W | 35 % | 0.5 W |
| **Total at the 5 V rail** | | | | | 1.8 W → 2.1 W from the pack |
| **Total from the pack while shuffling** | | | | | **≈ 4.1 W** |
| Idle (ESP32 + sensors + pixel) | | | | | ≈ 0.75 W |

* Energy per shuffle: 4.1 W × 75 s ≈ **310 J ≈ 0.085 Wh**.
* Pack energy: 2200 mAh × 11.1 V = 24.4 Wh; usable ≈ 80 % (cutoff 3.2 V/cell,
  ageing) ≈ 19.5 Wh.
* Shuffles per charge, back-to-back: ≈ 19.5 / 0.085 ≈ **≈ 230** (upper
  bound; ignores idle).
* A four-hour game evening with 40 shuffles: 40 × 0.085 + 4 h × 0.75 W =
  3.4 + 3.0 = **6.4 Wh → about 3 evenings per charge**.
* Charge time at 1 A: ≈ 2.5–3 h from empty.

These figures will move with the real duty cycle and motor currents; the
firmware's serial `stats` command prints measured shuffle time and battery
voltage so the estimate can be corrected after the first build.

## 4.5 Peak and stall currents [EST]

| Item | Stall / peak | Notes |
|---|---|---|
| NEMA 17 through TMC2208 | 0.65 A RMS set by Vref (0.9 A peak/phase) | Current is regulated by the driver; a stall does not raise it |
| MG90S | ≈ 0.7 A each at 5 V stall | Blade entry force is < 1 N; stall only on a jam |
| N20 6 V 300 rpm | ≈ 0.8–1.0 A each at 5 V stall | Firmware limits motor-on time (jam timeout) |
| Worst-case simultaneous | stepper move + both servos stalled + both N20 stalled | ≈ 5 W + 5 V × 3.4 A / 0.85 = 25 W ≈ **2.3 A from the pack** |

The 3 A fuse and a 3 A buck cover this. Pack BMS discharge limits of 5 A or
more are typical for 3S 18650 packs; check the listing.

## 4.6 Battery details

* **Pack**: 3S1P 18650 Li-ion, 11.1 V nominal, 2200–2600 mAh, with
  integrated protection board (over-charge, over-discharge, over-current,
  short circuit). Buy a pack that states its BMS discharge current (≥ 5 A)
  and comes with a connector (XT30 or JST-XH); do not build the pack from
  loose cells unless you are equipped to do so safely.
* **Mounting**: the pack sits in the front skirt under the hopper on a
  self-adhesive foam pad and is held by a Velcro strap through two slots
  (see assembly step 20). Keep it away from the motor bracket and route its
  leads to J1 on the perfboard.
* **Charging**: the panel-mounted 5.5×2.1 mm jack is wired to the pack
  terminals (through the BMS) upstream of the power switch; the 12.6 V 1 A
  adapter's own LED shows charge state. Charging with the machine switched
  off is recommended.
* **Low-battery behaviour** (firmware): warning colour below 9.9 V
  (3.3 V/cell); a new shuffle is refused below 9.6 V; if the voltage falls
  below 9.3 V during a shuffle the current card is completed (gap closed,
  blades retracted), the stack is presented, the drivers are disabled and a
  triple beep is issued. The BMS cuts off at about 2.5–3.0 V/cell as the
  last resort.
* **USB-C option (documented, not the primary design)**: replace the pack
  and charger with a USB-C PD power bank (20 W or more) plus a PD trigger
  module set to 12 V feeding the same VBAT bus. This gives USB-C charging
  and mains operation from a PD wall adapter. Drawbacks: the bank is
  external (a pocket in the skirt is easy to add), and many banks switch
  off below ~100 mA load, so the firmware's keep-alive option
  (`KEEPALIVE_MS`) pulses the stepper coils briefly every 10 s when
  enabled. Availability and prices of PD trigger boards were not verified
  in this design pass.
* **2S option**: a 2S pack (7.4 V) works with the TMC2208 but the elevator
  speed roughly halves; the A4988 cannot be used below 8 V.

## 4.7 Safety and shutdown

* The elevator lead screw is self-locking: on power loss the platform stays
  put and the deck does not fall.
* On any jam the firmware stops all motors within 50 ms, retracts the blades,
  disables the stepper driver and puts the DRV8833 to sleep; motors cannot
  restart until the button is pressed.
* The stepper driver is disabled whenever the machine is idle, so nothing
  gets hot.
* The button is the only user control; holding it for 3 s in an error state
  performs a homing cycle and lowers the platform for jam access.
* The rollers are under a lid and the well is open only at the top; no pinch
  point is reachable with a finger while the machine runs, but keep hair
  and clothing away from the open well.

## 4.8 Perfboard layout

A 70 × 50 mm perfboard carries the ESP32 (on female headers), the TMC2208
and DRV8833 (on female headers), the buck module, the NPN LED switch, the
voltage divider, pull-down resistors, and JST-XH headers for every external
connection (J1–J16, listed on the wiring diagram). Suggested placement:
ESP32 along one long edge with USB accessible through the skirt's side
cut-out; TMC2208 near the pack connector with the 100 µF capacitor next to
its VM pin; sensor headers along the opposite edge.

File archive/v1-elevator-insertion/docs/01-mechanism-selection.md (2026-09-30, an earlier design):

# 1. Mechanism selection

This document compares the feasible ways to shuffle one 52–54 card poker deck
with a machine a hobbyist can print and wire, and explains why this project
uses **single-card random-gap insertion** (an elevator well with separator
blades, executing the inside-out Fisher–Yates algorithm physically).

Everything here is a design analysis. Nothing in this repository has been
built and measured yet; the speed and reliability numbers are engineering
estimates and are labelled as such.

## 1.1 Requirements recap

| Requirement | Target | Notes |
|---|---|---|
| Deck | 52 cards, 54 if practical | Poker size 63.5 × 88.9 mm |
| Card thickness | 0.25–0.35 mm standard; 0.22–0.42 mm accepted | Custom printed decks tend to be thicker |
| Operation | Load, one button, collect | Minimal effort |
| Cycle time | < 30 s target, honest estimate required | See §1.6 |
| Randomness | Measurably close to uniform on all 52! orders | See `02-mathematics.md` |
| Card safety | No scratches, bent corners, exposed faces | |
| Power | Battery, rechargeable, protected pack | |
| Cost | < $130 excluding printing | |
| Build | Consumer FDM printer, hand tools, no machining | |

## 1.2 Candidate mechanisms

### A. Automated riffle (two hoppers, alternating feed)

This is the $20 consumer shuffler. The deck is split into two hoppers; a
roller on each hopper flicks cards into a centre tray, alternating between
the two sides.

* **Randomness.** The mathematical model for a hand riffle is the
  Gilbert–Shannon–Reeds (GSR) shuffle, which needs about 7 riffles for a
  52-card deck (Bayer & Diaconis 1992). Consumer riffle machines are far
  *less* random than GSR per pass, because the two rollers alternate almost
  perfectly (run lengths of 1–2 cards) and the cut is always near 26/26. A
  one-pass machine riffle leaves the deck with at most 2 rising sequences;
  the number of reachable permutations after one pass is tiny (≈2^52 out of
  8×10^67, and the actual distribution is much narrower than that).
* **To fix it** you must re-split and re-riffle 8–12 times. Automating the
  re-split requires a second mechanism that cuts a stack at a random depth
  and moves half of it, which is the hard part of any shuffler. Without it,
  the user has to split the deck by hand every pass, which fails the
  "one button" requirement.
* **Speed** is excellent per pass (3–5 s). **Card wear** is moderate: cards
  are bent as they are flicked. **Noise** is high. **Cost** is low.

### B. Random-bin routing ("shelf shuffler")

One feeder takes cards off the deck one at a time and a diverter drops each
card into one of N bins chosen at random. The bins are then stacked in a
fixed order. This is the casino "shelf shuffler" analysed by
Diaconis, Fulman & Holmes (2013).

* **Randomness.** One pass with N bins, each card going to a uniformly
  chosen bin and each bin keeping arrival order, is the inverse of an
  N-riffle (an "a-shuffle" with a = N in Bayer–Diaconis terms). Its distance
  from uniform is exactly that of an N-riffle: with N = 8 one pass is
  roughly as good as 3 hand riffles, which is *not* enough; four passes
  (8^4 = 4096-shuffle) reach total-variation distance ≈ 0.01. Diaconis,
  Fulman & Holmes showed that a real 10-shelf machine after one pass lets a
  player guess the next card far better than chance, and the manufacturer
  changed the machine to run two passes.
* **Mechanics.** A moving diverter or a moving bin stack, plus a way to
  recombine the bins. Recombining automatically means every bin needs its
  own feeder, or the bins must be re-fed through the machine (user
  intervention). Multi-pass makes a slow machine.
* Speed per pass ~15–20 s; 3–4 passes plus re-feeding: 60–80 s with user
  intervention.

### C. Random-slot carousel (one slot per card)

A rotating drum with 54 slots. Each card is fed into a random empty slot,
then the slots are ejected in order. Assigning each card to a uniformly
random free slot is a uniform permutation (it *is* Fisher–Yates).

* **Randomness.** Exact, in principle.
* **Size.** 54 cards standing radially need a drum of about Ø190–240 mm and
  95 mm height, plus a feeder, plus an output tray with a spring follower.
  This is the least compact option by far.
* **Mechanics.** Two positioning moves and two card pushes per card
  (in and out), so ~100 s per deck. Thin radial fins are printable but
  fragile. Ejecting a card standing on edge into a neat stack needs a
  spring-loaded output shoe.

### D. Single-card random-gap insertion (elevator well) — **selected**

One feeder takes the bottom card off the deck. The card is pushed into a
vertical well whose stack rests on an elevator. Before each card, the
elevator moves the stack so that a randomly chosen gap (between card k and
k+1, or below the bottom card, or above the top card) is level with a pair
of thin separator blades. The blades slide in from the sides, the elevator
drops the lower part of the stack by 3 mm, the new card slides into the gap,
the elevator closes the gap and the blades withdraw.

This is the architecture of the casino single-deck shufflers described in
Shuffle Master's elevator-insertion patents (see references) and of the
Shuffle Tech ST-1000 home unit (~$500), scaled down to hobby parts.

* **Randomness.** Inserting card i (i = 0..n−1) into a uniformly random one
  of the i+1 gaps of the current stack is the inside-out Fisher–Yates
  algorithm. Every permutation is reachable and, if each gap index is
  uniform and independent and the mechanism places the card where told,
  every permutation has probability exactly 1/52!. The physical error modes
  (a blade landing one gap off, a double feed) perturb this and are
  analysed and simulated in `02-mathematics.md`.
* **Mechanics.** One friction feeder, one transport roller, one lead-screw
  elevator (stepper), one micro servo for the blades. No card is ever bent
  or flicked. Cards are pushed edge-first on a flat guide.
* **Speed.** ~1.0–1.4 s per card, so 55–75 s per deck (estimate, §1.6).
* **Card wear.** Lowest of the options: rolling contact only, no bending,
  no flicking. The blades touch card edges only.
* **Noise.** Low (stepper hum, small DC motors, servo clicks).
* **Cost.** ~$100–115 in parts (see `05-bom.md`).
* **Complexity.** Medium. The two precision requirements are (1) feeding
  exactly one card and (2) positioning the elevator to ±0.15 mm so a blade
  enters the intended gap. Both are addressed with sensors and calibration
  (see `03-mechanical-design.md` §3.7 and `06-assembly.md` §6.9).

### E. Variants considered and rejected

* **Insertion without blades** (push the card into the stack edge and let
  it wedge its own gap): a 0.3 mm card buckles at ~0.5 N; lifting 40 cards
  plus edge friction needs more than that, and card edges are not aligned
  to 0.3 mm anyway. Not reliable.
* **Clamp the upper stack from the sides and drop the lower stack**: works
  in principle but the boundary between "held" and "dropped" cards is fuzzy
  (recessed cards are not clamped), so a card can be held on one side and
  dropped on the other and jam. Blades give a defined support surface.
* **Passive one-way blades** (cards ride up over them): cards can never
  come back down, so the gap position cannot be chosen freely. Active
  (servo) blades are required.
* **Two steppers or a belt elevator**: a lead screw is self-locking, so the
  stepper can be de-energised between moves, which saves battery.

## 1.3 Scoring

Scores 1 (poor) to 5 (excellent). These are judgement scores, not
measurements.

| Criterion | A. Riffle machine | B. Bin routing | C. Carousel | **D. Gap insertion** |
|---|---|---|---|---|
| Randomness per button press | 1 | 2 (3 with 4 auto passes) | 5 | **5** (exact algorithm; physical error modes bounded) |
| Speed | 5 | 3 | 2 | **3** |
| Cost | 5 | 3 | 2 | **3** |
| Size | 4 | 3 | 1 | **4** |
| Mechanical complexity | 4 | 2 | 2 | **3** |
| Card wear | 2 | 4 | 3 | **5** |
| Noise | 1 | 3 | 3 | **4** |
| Reliability (estimated) | 3 | 3 | 2 | **3** |
| One-button operation | 1 (needs re-splits) | 2 | 5 | **5** |
| **Weighted total** (randomness ×3, one-button ×2, others ×1) | 27 | 32 | 40 | **50** |

## 1.4 Selected architecture

```
                 lid + follower weight
     ┌────────────────────┐
     │  HOPPER (deck,     │  gate (adjustable 0.3–0.6 mm slot)
     │  face down)        │  │       idler
     │                    │  ▼        ▼    ┌──────────────────┐
     └──────┬──────┬──────┘ ═══▶ ═══════▶ │  WELL            │
        feed roller  transport roller     │  ┌────────────┐  │
        (N20 motor)  (N20 motor)          │  │ upper stack│◀─┼─ separator blades (servo)
                                          │  ├────────────┤  │   3 mm gap ← new card
   whole card path tilted 12°             │  │ lower stack│  │
   (cards slide to the back wall)         │  └────────────┘  │
                                          │   elevator platform (T8 lead screw + NEMA 17)
                                          └──────────────────┘
```

* **Feeder module**: hopper with weighted lid, bottom-feed friction roller,
  adjustable separation gate, transport roller with spring idler, gate
  beam sensor, hopper-empty beam sensor. Two N20 gear motors.
* **Well module**: card well, elevator (T8×8 lead screw, two 8 mm guide
  rods, NEMA 17), two separator-blade bars driven by one MG90S servo through
  a Scotch-yoke disc, well-slot beam sensor (card fully inserted), stack-top
  beam sensor (stack height measurement), bottom endstop switch.
* **Controller**: ESP32 DevKitC. Hardware RNG (ADC-noise entropy source
  enabled explicitly) → ChaCha20 DRBG → rejection sampling for unbiased
  gap indices. TMC2208 stepper driver, DRV8833 dual DC driver.
* **Power**: 3S Li-ion pack with BMS, 12.6 V barrel charger (USB-C PD
  option documented).

## 1.5 Why the 12° tilt

The whole card path (hopper floor, guide plate, well axis) is tilted 12°
so that the well is the low end. Three benefits:

1. The transport roller releases the card about 13 mm before its leading
   edge reaches the back wall. On a level guide (μ ≈ 0.3 card-on-card)
   a card leaving at 0.25 m/s coasts only ~10 mm. At 12° the net
   deceleration drops to about 0.85 m/s² and the card coasts > 35 mm, so
   every card seats fully against the padded back wall.
2. Cards in the well settle against the back wall under gravity, which
   keeps the stack's edges aligned. Aligned edges are what lets a 0.5 mm
   blade enter a chosen gap reliably.
3. The deck in the hopper slides against the gate, so feeding does not
   depend on the user pushing the deck forward.
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

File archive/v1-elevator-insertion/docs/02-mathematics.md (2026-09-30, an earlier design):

# 2. Mathematics of the shuffle

This document separates four kinds of statements and labels each:

* **[PROOF]** — a mathematical statement that holds for the idealised model.
* **[SIM]** — a Monte-Carlo result from `simulation/shuffle_sim.py`
  (results in `simulation/results/full_results.txt`).
* **[EST]** — an engineering estimate.
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

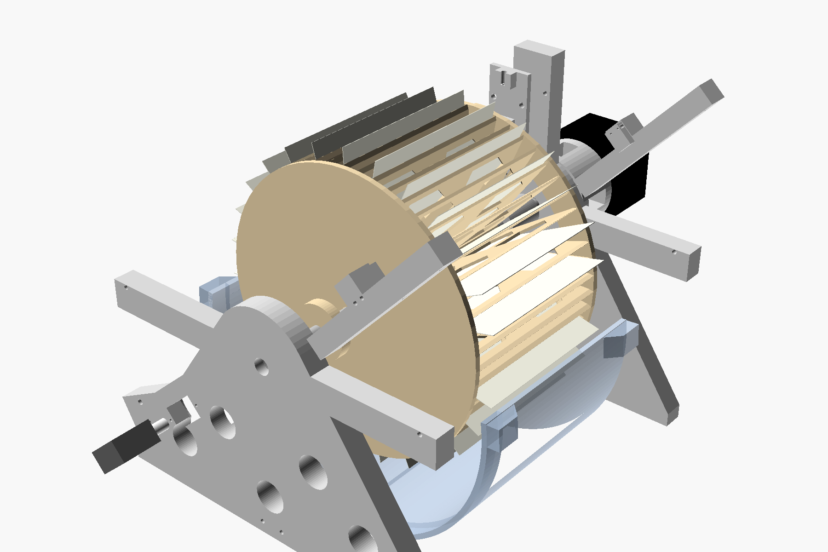
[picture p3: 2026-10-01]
cad/png/wheel_exploded.png

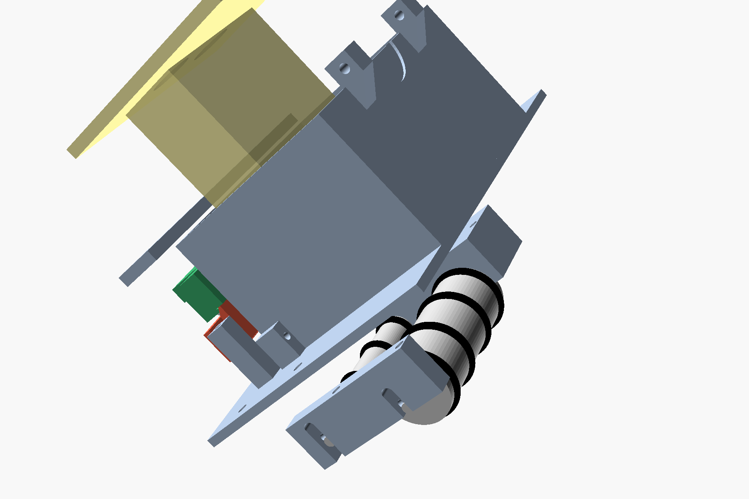
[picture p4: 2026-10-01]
cad/png/feeder_exploded.png

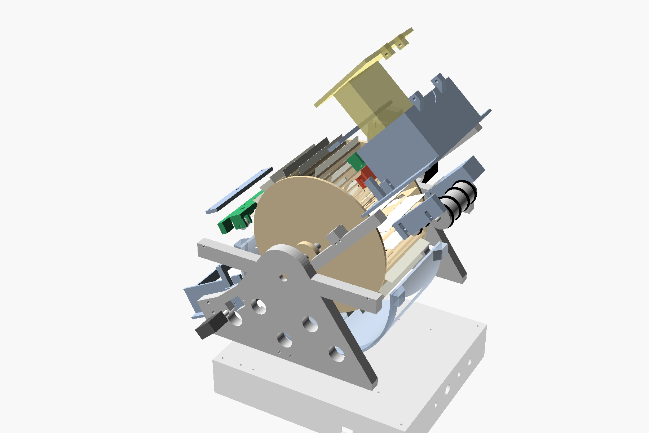
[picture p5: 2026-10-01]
cad/png/exploded.png

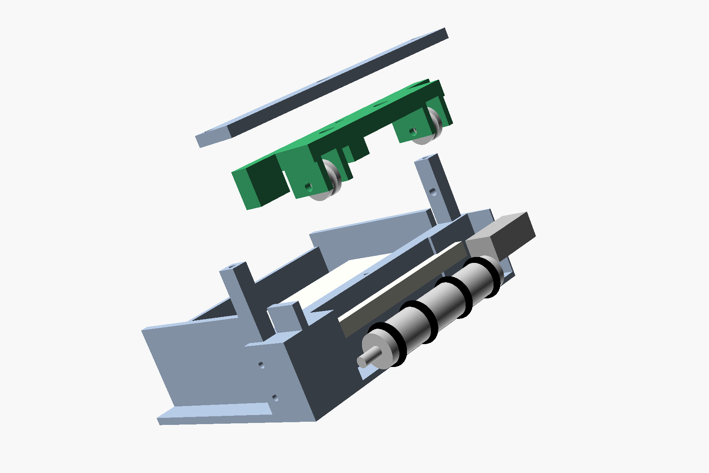
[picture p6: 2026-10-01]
cad/png/exit_exploded.png

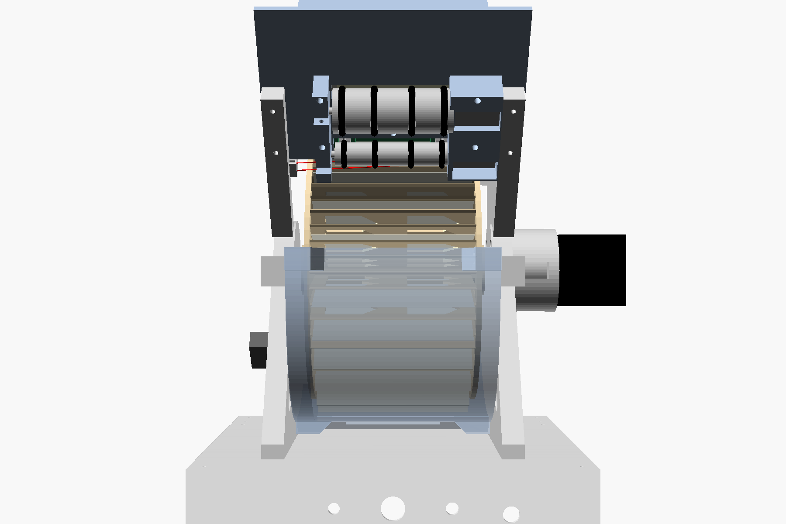
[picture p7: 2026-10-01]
cad/png/front.png

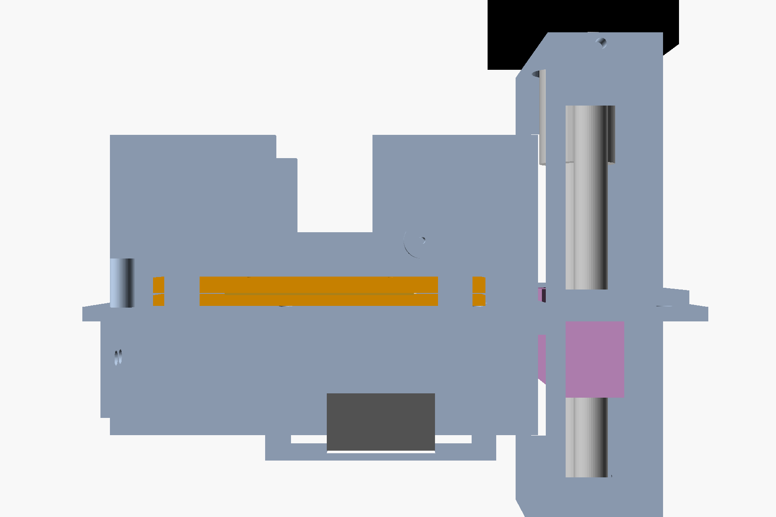
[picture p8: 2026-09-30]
cad/png/well_section_front.png

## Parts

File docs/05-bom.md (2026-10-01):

# 5. Bill of materials

Machine-readable copy: `electronics/bom.csv`. USD estimates for single
quantities from hobby suppliers; "verified" = a price in that range was
seen in a supplier listing in September 2026, "typical" = from experience.
Shipping and printing excluded.

## 5.1 Electronics

| # | Item | Qty | Spec | Alternatives | Est. | Status |
|---|---|---|---|---|---|---|
| E1 | ESP32 DevKitC V4 | 1 | WROOM-32, 30-pin | ESP32-S3 | $6 | verified $5–10 |
| E2 | TMC2208 stepstick | 1 | standalone | A4988 (3S only) | $5 | verified $4–20 |
| E3 | NEMA 17 stepper | 1 | 1.5–1.7 A | 17HS4023 | $10 | typical |
| E4 | 5→8 mm flexible coupler | 1 | 19 × 25 | rigid | $2.50 | typical |
| E5 | M8 threaded rod 200 mm, 4 nyloc nuts, 6 washers | 1 | zinc | 8 mm rod + flat | $2 | typical |
| E6 | 608ZZ bearing | 2 | 8×22×7 | 608-2RS | $1.50 | typical |
| E7 | MG90S servo | 1 | metal gear | SG90 | $3 | verified $2.6–3.5 |
| E8 | N20 gearmotor 6 V 300 rpm | 3 | 3 mm D-shaft | 200–500 rpm | $12 | partly verified |
| E9 | DRV8833 module | 2 | dual H-bridge | TB6612FNG | $6 | verified $2–5 ea |
| E10 | 3S Li-ion pack with BMS | 1 | 2200–2600 mAh, ≥ 5 A | any protected 3S ≤ 75×60×22 | $18 | typical |
| E11 | 12.6 V 1 A charger | 1 | 5.5×2.1 | 2 A | $6 | verified $4–19 |
| E12 | Panel DC jack | 1 | 5.5×2.1 | | $1 | typical |
| E13 | Buck 5 V 3 A | 1 | MP1584/LM2596 | fixed 5 V | $2 | typical |
| E14 | Toggle switch | 1 | ≥ 3 A | rocker | $1.50 | typical |
| E15 | Push button 12 mm | 1 | | arcade | $2 | typical |
| E16 | WS2812B pixel | 1 | | 3 LEDs | $1 | typical |
| E17 | Passive piezo | 1 | | active | $1 | typical |
| E18 | IR LED 3 mm 940 nm | 5 | TSAL4400 / IR204 (beams B, E, S, X, index) | 5 mm | $1.75 | verified |
| E19 | IR phototransistor 3 mm | 5 | TEFT4300 / PT204 | 5 mm | $2.00 | verified |
| E21 | NPN 2N2222 | 1 | | N-MOSFET | $0.20 | typical |
| E22 | Resistors | set | 150×2, 68×2, 330×2, 470, 10 k×5, 100 k, 33 k, 100 | | $1 | typical |
| E23 | Capacitors | set | 100 µF×3, 470 µF, 100 nF×3 | | $1 | typical |
| E24 | Perfboard, headers, JST-XH kit, wire | 1 | | Dupont | $8 | typical |
| E25 | Polyfuse 3 A | 1 | | blade | $1 | typical |
| | **Electronics subtotal** | | | | **≈ $95.50** | |

## 5.2 Mechanical

| # | Item | Qty | Spec | Alternatives | Est. | Status |
|---|---|---|---|---|---|---|
| M1 | O-ring ID 20 × 3.5 | 5 | feed roller | silicone | $2 | typical (assortment ≈ $8 covers M1–M3) |
| M2 | O-ring ID 10 × 3.0 | 9 | nip rollers | | $2.25 | typical |
| M3 | O-ring 9 × 2 | 4 | idlers | none | $0.80 | typical |
| M4 | Self-adhesive felt 1.5 mm | 1 | chute wall, lid pad | EVA | $3 | typical |
| M5 | M3 screw assortment | 1 | ~80 pcs (6–20 mm) + M3 × 40 ×4, × 50 ×2, × 60 ×1, nuts, 3 grubs | inserts | $8 | typical |
| M6 | M2 × 8 / M2 × 12 | 4 + 1 | servo flange, horn pin (12 mm) | | $0.60 | typical |
| M7 | Pen springs | 4 | idler pressure | rubber bands | $0 | scrap |
| M8 | Dead AA cells | 2 | lid ballast | coins | $0 | scrap |
| M9 | Velcro strap + foam | 1 | battery | zip ties | $2 | typical |
| | **Mechanical subtotal** | | | | **≈ $19** | |

## 5.3 Totals

| | |
|---|---|
| Everything new, single quantities | **≈ $114** |
| With a normal parts drawer (E22–E24, M5) | ≈ $96 |
| Cheapest configuration (A4988, SG90, 17HS4023, skate bearings, printed idlers) | ≈ $88 |
| Optional TCRT5000 | +$1 |

Compared with v1: no brass blades, no lead screw, rods or LM8UU, one servo
instead of two; one more N20, one more DRV8833, two more IR pairs, an M8
rod and two bearings. Net ≈ −$6.

## 5.4 Sourcing notes

* "Ender-3 Z-axis kit" listings contain the 5→8 mm coupler.
* Skateboard bearings are 608 (any grade works).
* N20 motors: choose the 9 mm D-shaft version; 3 identical motors keep the
  BOM simple, and the feed roller runs at lower PWM.
* The index sensor is a bare LED and phototransistor pair in the printed
  index bracket. A slotted module cannot straddle the tab without its inner
  arm hitting the disc.

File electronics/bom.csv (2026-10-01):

id | item | qty | specification | compatible_alternatives | est_unit_usd | est_total_usd | example_sources | price_status
E1 | ESP32 DevKitC V4 (WROOM-32 30-pin) | 1 | ESP32-WROOM-32, CP2102/CH340 USB, 30-pin | ESP32-S3 DevKitC (pin remap) | 6.00 | 6.00 | eBay ~$5, LCSC $8.7, Mouser $10 | verified 2026-09 (range)
E2 | TMC2208 stepper driver stepstick | 1 | standalone mode, with heatsink | A4988 or DRV8825 (3S pack only) | 5.00 | 5.00 | UK £3.25-4.45, US $6-20 | verified (range)
E3 | NEMA 17 stepper motor | 1 | 42 mm, 1.5-1.7 A, 4-wire, 5 mm shaft (17HS4401 class) | 17HS4023 (1 A) with Vref 0.7 V | 10.00 | 10.00 | StepperOnline, Amazon, AliExpress | unverified (typical)
E4 | Shaft coupler 5 mm to 8 mm | 1 | flexible aluminium 19 x 25 mm | rigid coupler | 2.50 | 2.50 | Ender-3 Z-axis kits include one | unverified
E5 | M8 threaded rod 200 mm + 4 nyloc nuts + 6 washers | 1 | zinc plated, cut to 165 mm | 8 mm smooth rod with a filed flat and set screws | 2.00 | 2.00 | hardware store | unverified
E6 | 608ZZ bearing | 2 | 8 x 22 x 7 mm | 608-2RS | 0.75 | 1.50 | skate bearings, Amazon 10-pack ~$7 | unverified
E7 | MG90S micro servo | 1 | metal gear, 180 deg, with horns | SG90 | 3.00 | 3.00 | Waveshare $2.59, eBay 4-pack $13.95 | verified
E8 | N20 micro gearmotor 6 V 300 rpm | 3 | N20 metal gearbox, 3 mm D-shaft | N20 200-500 rpm | 4.00 | 12.00 | Robu.in ~$3, Amazon 2-packs ~$9 | partly verified
E9 | DRV8833 dual H-bridge module | 2 | 2.7-10.8 V, 1.5 A/ch | TB6612FNG module | 3.00 | 6.00 | Pololu $4.95, generic $2-3 | verified (range)
E10 | 3S Li-ion battery pack with BMS | 1 | 11.1 V 2200-2600 mAh 18650 3S1P, BMS >= 5 A, XT30 or JST-XH | any protected 3S pack <= 75 x 60 x 22 mm | 18.00 | 18.00 | Amazon, robotics suppliers | unverified (typical)
E11 | 12.6 V 1 A Li-ion charger | 1 | CC/CV, 5.5x2.1 barrel | 12.6 V 1.5-2 A | 6.00 | 6.00 | eBay £3-4 to $19 | verified (range)
E12 | DC barrel jack panel mount 5.5x2.1 | 1 | with nut | — | 1.00 | 1.00 | any | unverified
E13 | Buck converter 5 V 3 A | 1 | MP1584EN or LM2596 adjustable | fixed 5 V 3 A module | 2.00 | 2.00 | any | unverified
E14 | Toggle switch SPST | 1 | >= 3 A DC, 6 mm bushing | rocker | 1.50 | 1.50 | any | unverified
E15 | Push button momentary 12 mm | 1 | panel mount | arcade button | 2.00 | 2.00 | any | unverified
E16 | WS2812B pixel breakout | 1 | single pixel | 3 LEDs | 1.00 | 1.00 | any | unverified
E17 | Passive piezo buzzer | 1 | 5 V passive | active buzzer | 1.00 | 1.00 | any | unverified
E18 | IR LED 940 nm 3 mm | 5 | TSAL4400 / IR204 | 5 mm (enlarge holes) | 0.35 | 1.75 | DigiKey/RS $0.25-0.45 | verified (range)
E19 | IR phototransistor 3 mm | 5 | TEFT4300 / PT204-6B | 5 mm PT334 | 0.40 | 2.00 | DigiKey/RS ~$0.30 | verified (range)
E21 | NPN transistor 2N2222 / BC547 | 1 | TO-92 | logic-level N-MOSFET | 0.20 | 0.20 | any | unverified
E22 | Resistor set | 1 | 150 x2, 68 x2, 330 x2, 470, 10 k x5, 100 k, 33 k, 100 ohm | — | 1.00 | 1.00 | any | unverified
E23 | Capacitors | 1 | 100 uF 25 V x3, 470 uF 10 V, 100 nF x3 | — | 1.00 | 1.00 | any | unverified
E24 | Perfboard 70x50 + headers + JST-XH kit + wire | 1 | female headers, JST-XH 2.54 crimp kit, 22-24 AWG | Dupont | 8.00 | 8.00 | any | unverified
E25 | Polyfuse 3 A | 1 | resettable, or blade fuse holder + 3 A | — | 1.00 | 1.00 | any | unverified
M1 | O-rings ID 20 x CS 3.5 mm nitrile | 5 | feed roller (4 + spare) | silicone | 0.40 | 2.00 | metric O-ring assortment ~$8 covers M1-M3 | unverified
M2 | O-rings ID 10 x CS 3.0 mm nitrile | 9 | two nip rollers (8 + spare) | — | 0.25 | 2.25 | assortment | unverified
M3 | O-rings 9 x 2 mm | 4 | idler wheels | plain printed wheels | 0.20 | 0.80 | assortment | unverified
M4 | Self-adhesive felt sheet 1.5 mm | 1 | chute end wall, lid pad, optional shroud lining | EVA foam | 3.00 | 3.00 | any | unverified
M5 | M3 screw assortment | 1 | M3 x 6/8/10/12/16/20 (~80 pcs), M3 x 40 x4, M3 x 50 x2, M3 x 60 x1, nuts, 3 grub | heat-set inserts optional | 8.00 | 8.00 | any | unverified
M6 | M2 screws | 5 | M2 x 8 x4 servo flange, M2 x 12 x1 horn pin | — | 0.10 | 0.60 | any | unverified
M7 | Compression springs from ballpoint pens | 4 | ~5 mm OD, 15 mm | rubber bands | 0.00 | 0.00 | scrap | —
M8 | AA cells (dead) for lid ballast | 2 | any | coins/washers | 0.00 | 0.00 | scrap | —
M9 | Velcro strap + foam pad | 1 | battery retention | zip ties | 2.00 | 2.00 | any | unverified
O1 | TCRT5000 module (optional deck-loaded sensor) | 1 |  | — | 1.00 | 1.00 | any | unverified

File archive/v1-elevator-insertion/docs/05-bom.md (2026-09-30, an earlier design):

# 5. Bill of materials

Machine-readable copy: `electronics/bom.csv`. Prices are USD estimates for
single quantities from hobby suppliers (Amazon/eBay/AliExpress/DigiKey);
"verified" means a price in that range was seen in a supplier listing during
this design pass (September 2026), "unverified" means a typical price from
experience. Shipping and 3D printing are excluded. Nearly every item has a
cheaper multi-pack option.

## 5.1 Electronics

| # | Item | Qty | Specification | Alternatives | Est. | Status |
|---|---|---|---|---|---|---|
| E1 | ESP32 DevKitC V4 | 1 | WROOM-32, 30-pin, USB serial | ESP32-S3 DevKitC | $6 | verified $5–10 |
| E2 | TMC2208 stepstick | 1 | standalone, with heatsink | A4988, DRV8825 | $5 | verified $4–20 |
| E3 | NEMA 17 stepper | 1 | 1.0–1.7 A, 4-wire (17HS4401 / 17HS4023) | integrated lead-screw motor (LDO, $33) | $10 | typical |
| E4 | T8×8 lead screw 100 mm + brass nut | 1 | Tr8×8, flanged nut | T8×2 | $6 | verified $4–7 |
| E5 | 5→8 mm flexible coupler | 1 | 19 × 25 mm | (in some E4 kits) | $2.50 | typical |
| E6 | 8 mm × 100 mm rod | 2 | hardened steel | stainless | $5 | typical |
| E7 | LM8UU bearing | 2 | 8×15×24 | printed bushing | $2 | typical |
| E8 | MG90S servo | 2 | metal gear | SG90 | $6 | verified $2.6–3.5 ea |
| E9 | N20 gearmotor 6 V 300 rpm | 2 | 3 mm D-shaft | 200–500 rpm | $8 | partly verified |
| E10 | DRV8833 module | 1 | dual H-bridge | TB6612FNG | $3 | verified $2–5 |
| E11 | 3S Li-ion pack with BMS | 1 | 11.1 V, 2200–2600 mAh, ≥ 5 A BMS | any protected 3S pack ≤ 75×60×22 mm | $18 | typical |
| E12 | 12.6 V 1 A charger, 5.5×2.1 plug | 1 | CC/CV adapter | 12.6 V 2 A | $6 | verified $4–19 |
| E13 | Panel DC jack 5.5×2.1 | 1 | | | $1 | typical |
| E14 | Buck module 5 V 3 A | 1 | MP1584/LM2596 | fixed 5 V | $2 | typical |
| E15 | Toggle switch SPST | 1 | ≥ 3 A | rocker | $1.50 | typical |
| E16 | Push button 12 mm | 1 | momentary | arcade | $2 | typical |
| E17 | WS2812B pixel | 1 | | 3 LEDs | $1 | typical |
| E18 | Passive piezo | 1 | | active buzzer | $1 | typical |
| E19 | IR LED 3 mm 940 nm | 3 | TSAL4400 / IR204 | 5 mm | $1.05 | verified |
| E20 | IR phototransistor 3 mm | 3 | TEFT4300 / PT204 | 5 mm | $1.20 | verified |
| E21 | Lever microswitch | 1 | KW11/KW12 | optical endstop | $0.50 | typical |
| E22 | NPN 2N2222 | 1 | | N-MOSFET | $0.20 | typical |
| E23 | Resistors | set | 150 Ω×3, 1 k, 10 k×4, 100 k, 33 k, 330, 100 | | $1 | typical |
| E24 | Capacitors | set | 100 µF/25 V ×2, 470 µF, 100 nF ×3 | | $1 | typical |
| E25 | Perfboard, headers, JST-XH kit, wire | 1 | 70×50 mm | Dupont | $8 | typical |
| E26 | Polyfuse 3 A | 1 | | blade fuse | $1 | typical |
| | **Electronics subtotal** | | | | **≈ $100** | |

## 5.2 Mechanical

| # | Item | Qty | Specification | Alternatives | Est. | Status |
|---|---|---|---|---|---|---|
| M1 | O-ring ID 20 × CS 3.5 nitrile | 6 | rollers (2 spare) | silicone | $2.40 | typical (assortment ≈ $8 covers M1+M2) |
| M2 | O-ring 9 × 2 | 2 | idler wheels | none | $0.40 | typical |
| M3 | Brass sheet 0.5 mm | 1 | 100×100 mm, cut 2 blades 40×30 | feeler-gauge set ($7, verified) | $6 | partly verified |
| M4 | Self-adhesive felt 1.5 mm | 1 | back pad, lid pad | EVA foam | $3 | typical |
| M5 | M3 screw assortment | 1 | M3×6…20, ×50, ×60, nuts, 4 grub | heat-set inserts optional | $7 | typical |
| M6 | M2×8 screws | 4 | servos, endstop | | $0.40 | typical |
| M7 | Pen springs | 2 | idler pressure | rubber band | $0 | scrap |
| M8 | Dead AA cells | 2 | lid ballast | coins | $0 | scrap |
| M9 | Velcro strap + foam pad | 1 | battery retention | zip ties | $2 | typical |
| | **Mechanical subtotal** | | | | **≈ $21** | |

## 5.3 Totals

| | |
|---|---|
| Parts total, buying everything new in single quantities | **≈ $121** |
| If you already have screws, wire, perfboard, resistors, capacitors (E23–E25, M5) | ≈ $104 |
| Cheapest configuration (A4988, SG90 ×2, feeler-gauge blades, printed bushings) | ≈ $95 |
| Optional TCRT5000 deck sensor | +$1 |
| Optional heat-set inserts (20) | +$5 |

Printing: about 650 g of filament (PETG or PLA) for all parts; not costed.

## 5.4 Sourcing notes

* Lead screw kits sold for Ender-3 Z axes ("T8 8 mm lead 100/150 mm with
  nut, coupler, bearing") contain E4 + E5.
* Buy the O-rings as a metric assortment kit; sizes are not critical
  (ID 19–21 mm, cross-section 3.0–3.5 mm all fit the groove).
* Choose N20 motors with the 9 mm D-shaft; some listings have a 10 mm
  round shaft (then use the roller's set screw only).
* The 3S pack must physically fit 75 × 60 × 22 mm; verify before buying.
* Supplier links checked during design: see the reference list in
  `docs/10-deliverables-and-gaps.md`.

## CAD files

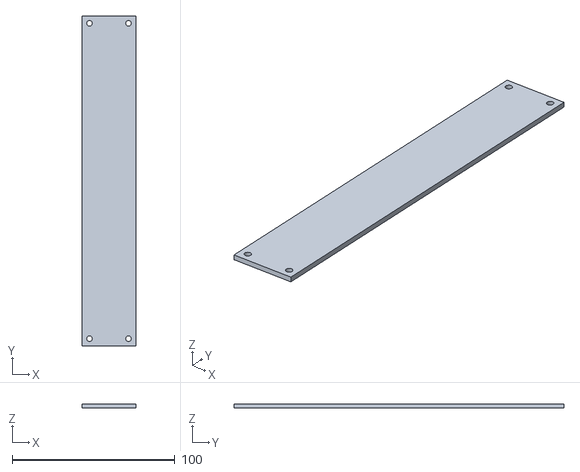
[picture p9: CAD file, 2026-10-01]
cad/stl/base_cover_rear.stl
33.0 x 203.0 x 2.50

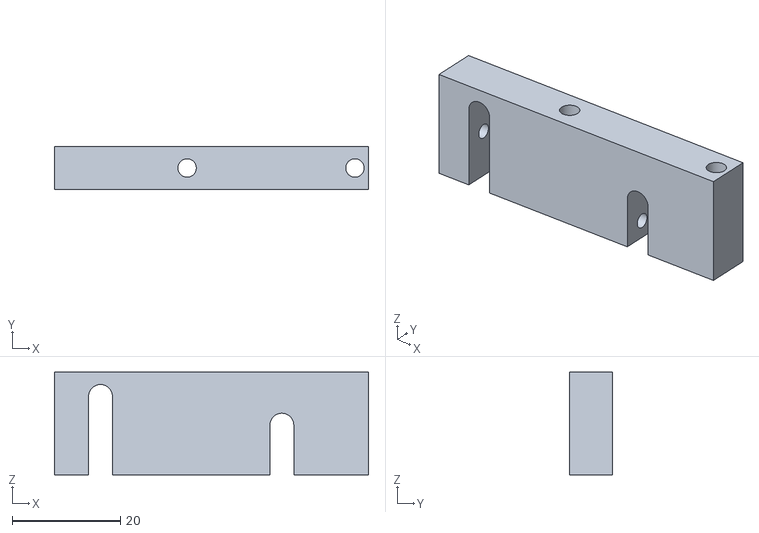
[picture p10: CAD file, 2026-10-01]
cad/stl/feeder_bushing_bracket.stl
58.0 x 8.00 x 19.0

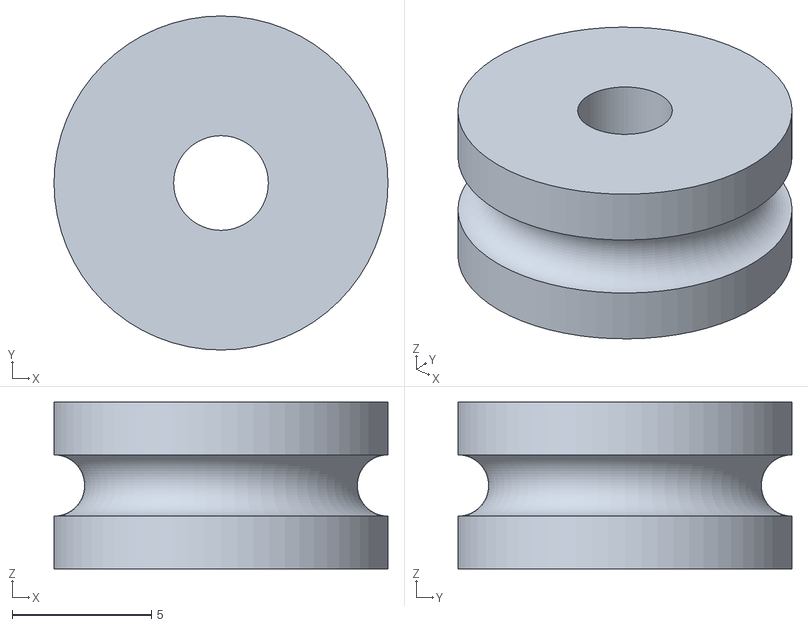
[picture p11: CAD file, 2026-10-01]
cad/stl/idler_wheel.stl
12.0 x 12.0 x 6.00

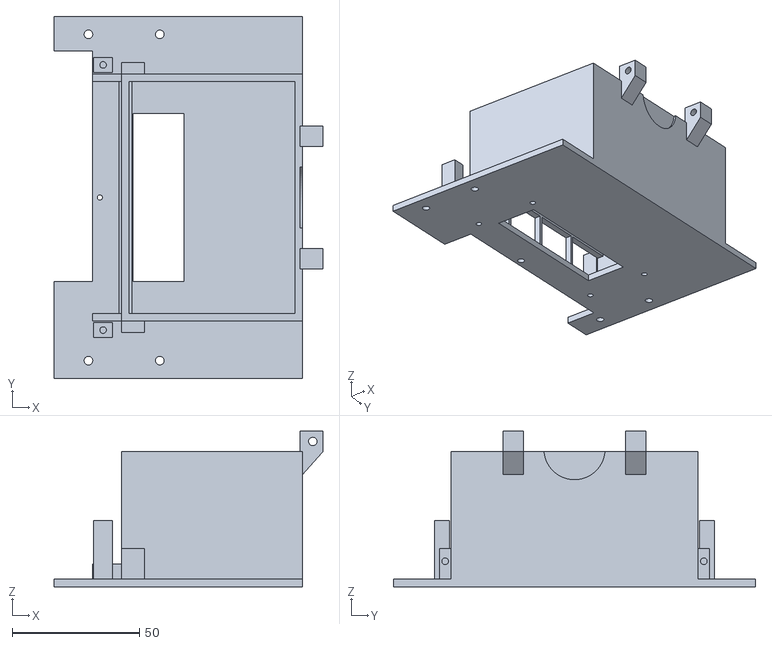
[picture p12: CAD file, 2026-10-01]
cad/stl/feeder_deck.stl
105.5 x 142.0 x 61.0

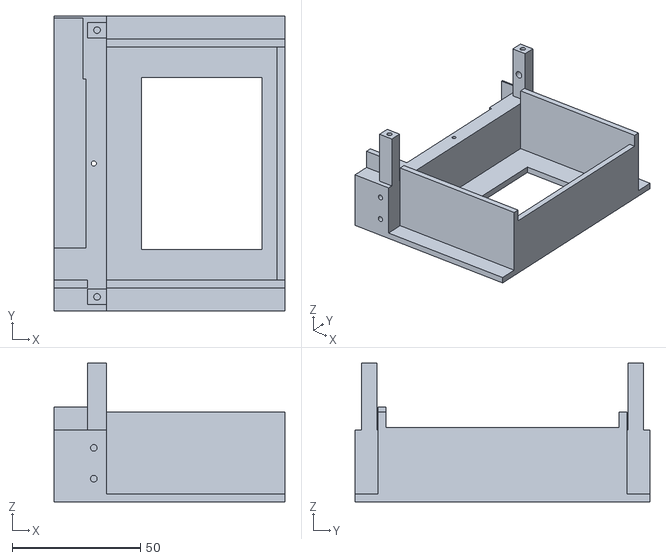
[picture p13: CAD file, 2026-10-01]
cad/stl/chute.stl
90.0 x 115.0 x 54.0

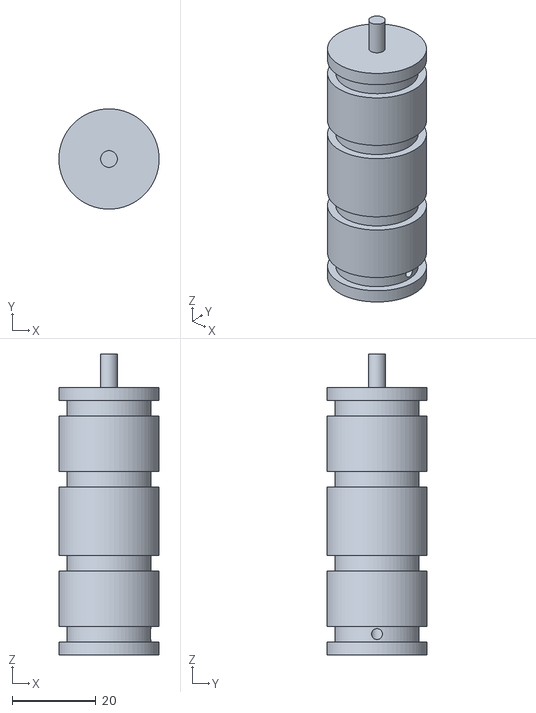
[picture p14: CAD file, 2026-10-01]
cad/stl/roller_feed.stl
24.0 x 24.0 x 72.0

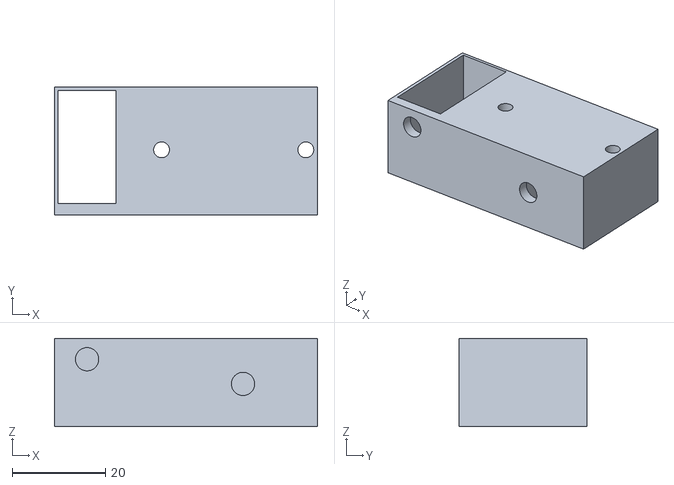
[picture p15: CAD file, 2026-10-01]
cad/stl/feeder_motor_bracket.stl
56.5 x 27.5 x 19.0

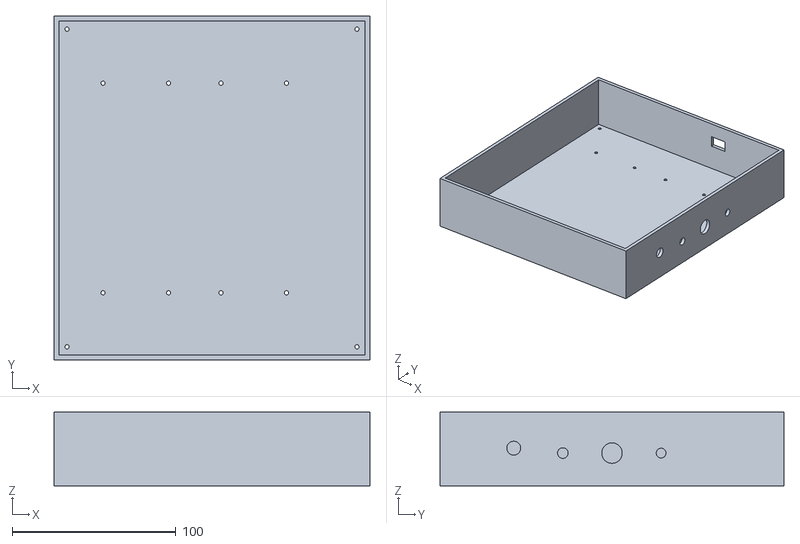
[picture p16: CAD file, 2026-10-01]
cad/stl/base_front.stl
193.0 x 210.0 x 45.0

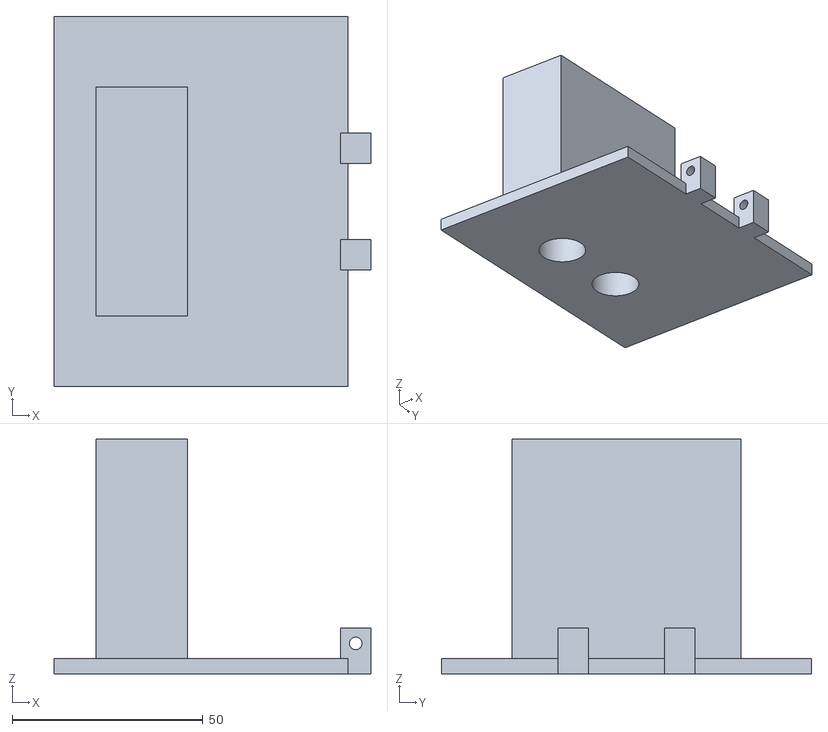
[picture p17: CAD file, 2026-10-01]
cad/stl/lid.stl
83.0 x 97.0 x 61.5

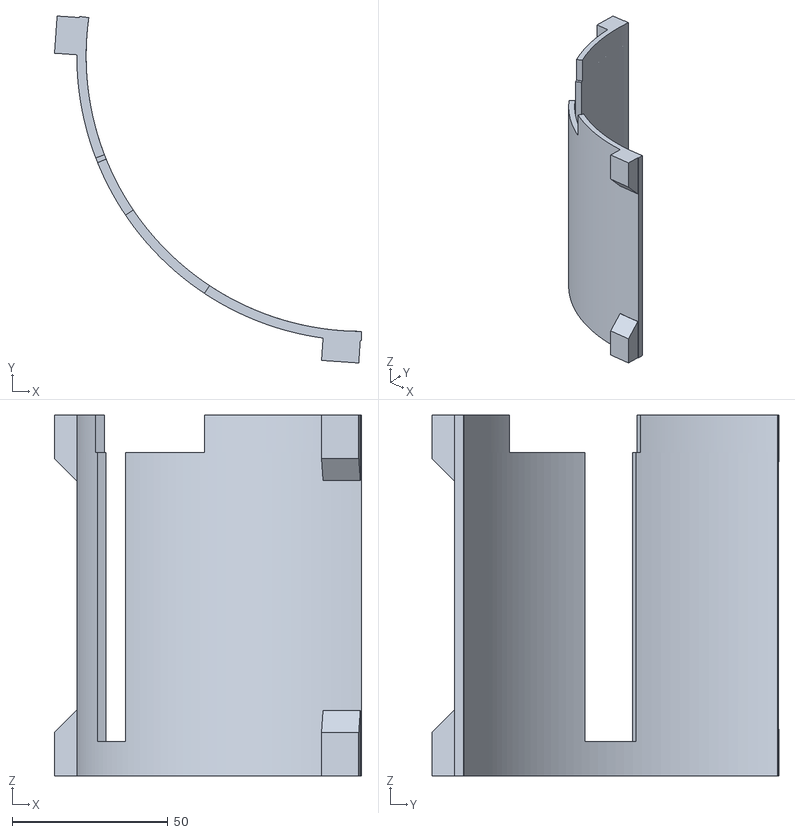
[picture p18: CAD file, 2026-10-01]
cad/stl/shroud_A.stl
98.7 x 111.5 x 116.0

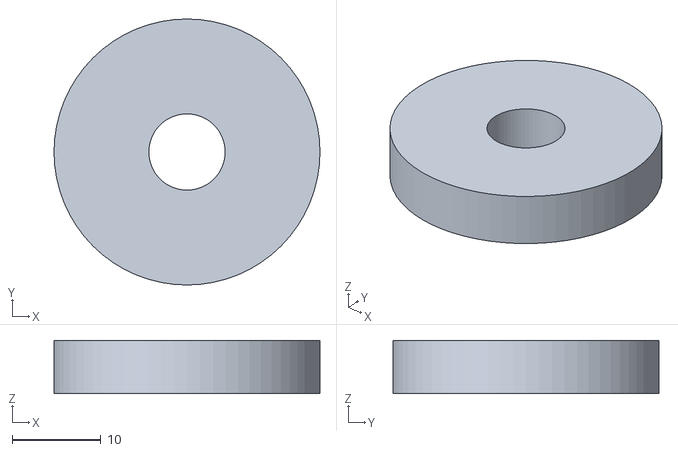
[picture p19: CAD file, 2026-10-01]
cad/stl/hub_spacer.stl
30.0 x 30.0 x 6.00

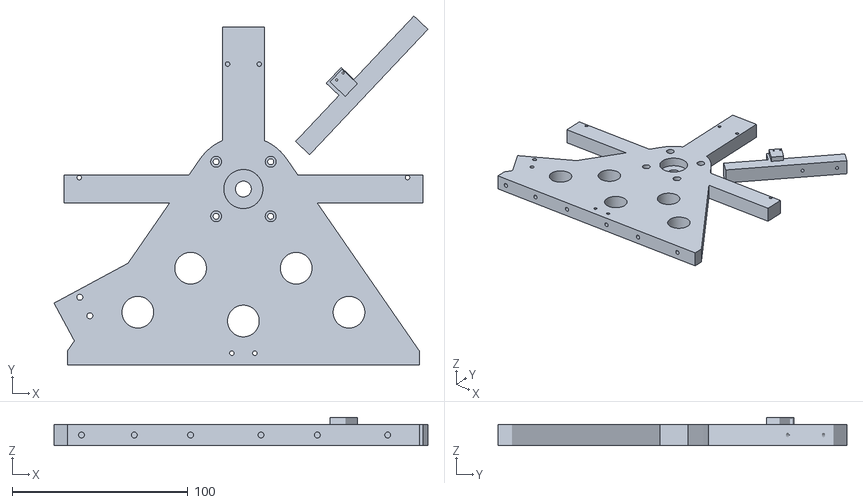
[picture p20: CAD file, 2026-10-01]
cad/stl/tower_R.stl
212.5 x 198.3 x 16.0

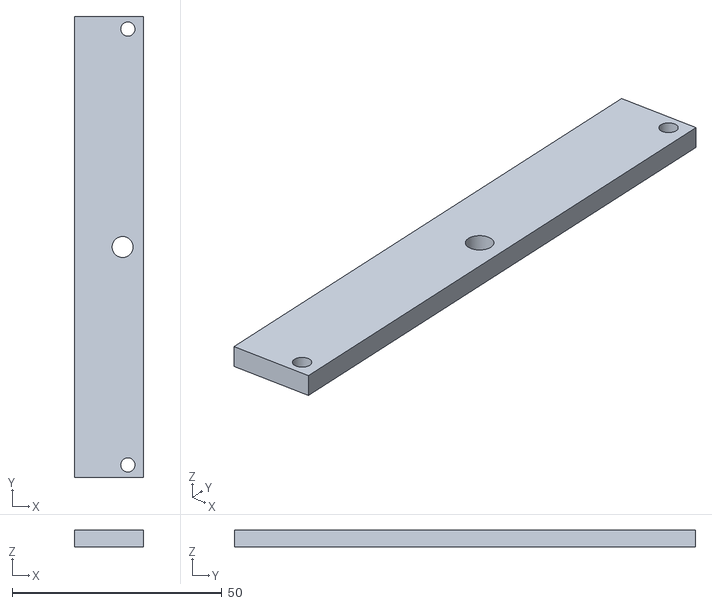
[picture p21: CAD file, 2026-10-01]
cad/stl/spring_bar.stl
16.5 x 110.0 x 4.00

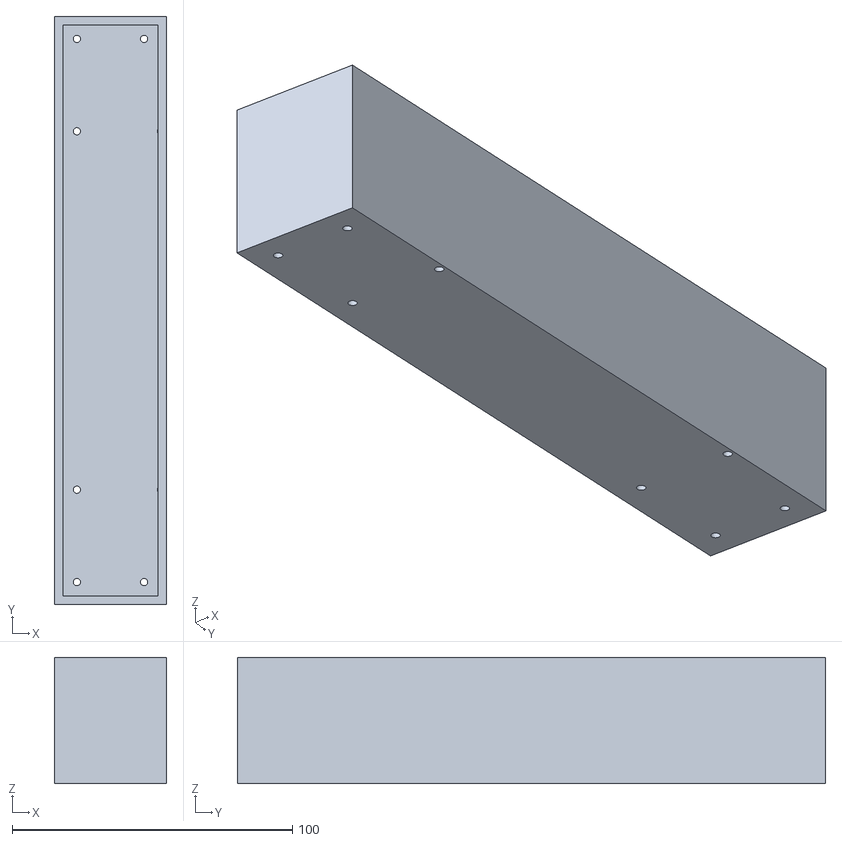
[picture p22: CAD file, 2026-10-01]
cad/stl/base_rear.stl
40.0 x 210.0 x 45.0

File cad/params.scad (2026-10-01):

// params.scad — every dimension of the WHEEL card shuffler (mm).
//
// Frame: the wheel axis is the Y axis, horizontal.  X is horizontal, Z is up, origin on the axis.
// Angles are measured in the XZ plane from +X (3 o'clock) counter-clockwise: 90° = 12 o'clock,
// 180° = 9 o'clock, 270° = 6 o'clock.  "Fin k" is a radial plate whose counter-clockwise face lies
// exactly on the radial plane at angle (wheel_angle + k*pitch_deg); slot k is the space between
// fin k and fin k+1.  A card in slot k lies on fin k at the entry (upper right) and on fin k+1 at
// the exit (lower left).  Cards enter and leave radially, lying flat on a fin.

// ---- cards -------------------------------------------------------------------
card_w      = 63.5;   // radial extent in the wheel (short edge)
card_l      = 88.9;   // axial extent (long edge, along Y)
card_t_max  = 0.42;
n_slots     = 54;
pitch_deg   = 360 / n_slots;    // 6.667°

// ---- wheel (cage) ----------------------------------------------------------------
r_hub       = 22;      // outer radius of the hub tube = card inner-edge stop
hub_wall    = 2;
r_seat_out  = r_hub + card_w;          // 85.5 outer edge of a seated card
r_tip       = r_seat_out - 8;          // 77.5 fin tips and disc radius (cards overhang 8 mm)
fin_t       = 1.4;                     // constant fin thickness (slot at hub = 2.56 - 1.4 = 1.16)
cage_w      = card_l + 3.1;            // 92 clear width between the discs
disc_t      = 3;
disc_ring_in= 62;                      // spoked disc: ring from here to r_tip
n_spokes    = 6;
hub_boss_r  = 15;  hub_boss_len = 6;   // bosses outside the discs (nuts clamp against them)
bore_d      = 8.6;                     // M8 threaded rod
index_ang   = 90;  index_r0 = 66; index_r1 = 76; index_w = 4;   // home tab on the +Y disc face (inside the disc rim, clear of beam E)
index_led_r = 59;  index_pt_r = 83;  index_beam_y = 51;             // radial index beam across the tab's path (+Y side, 12 o'clock)

// ---- shroud (retains cards in the lower half) ------------------------------------
r_shroud_in = r_seat_out + 3;          // 88.5
shroud_t    = 3;
shroud_w    = 92;                      // axial width: covers the card edges (|Y| <= 46 incl. play); discs are inside r 77.5
shroud_a0   = 172;  shroud_a1 = 368;   // arc covered (two segments split at 270°)
win_a0      = 202;  win_a1 = 214;      // exit window
// Shutter: a thin curved blade riding on the shroud's INNER surface.  Closed, it covers the window so a
// card edge rides over it on ramps (no edge to catch); open, it slides counter-clockwise past the window.
shut_r_in   = 87.0;  shut_r_out = r_shroud_in - 0.3;     // blade 87.0 .. 88.2
shut_ramp   = 2.6;                     // degrees of taper at each end (thickness 1.2 -> 0.4)
shut_a0     = win_a0 - shut_ramp;      // 199.4  closed: blade 199.4 .. 216.6
shut_a1     = win_a1 + shut_ramp;      // 216.6
shutter_open_deg = 17.5;               // opening slide, counter-clockwise
shut_hw     = 48.5;                    // blade half width (shroud is ±46; the blade overhangs it beside the discs' rims)
shut_tab_a  = 213;  shut_tab_r0 = 82; shut_tab_r1 = 91.5;   // drive tab at the -Y end (closed position)
shut_pin_r  = 86.75;                   // nominal pin radius on the tab
horn_r      = 18;                      // servo horn pin radius
// servo axis: on the perpendicular bisector of the pin's two end positions, inside the pin arc
shut_mid_a  = shut_tab_a + shutter_open_deg/2;                                 // 221.75°
shut_skirt_a1 = shut_tab_a + shutter_open_deg + 3 + 3;                        // -Y shroud skirt left off from the window to here (drive tab travel)
shut_half_chord = shut_pin_r * sin(shutter_open_deg/2);
servo_ax_r  = shut_pin_r * cos(shutter_open_deg/2) - sqrt(horn_r*horn_r - shut_half_chord*shut_half_chord);   // ≈ 73.4

// ---- entry (feeder) --------------------------------------------------------------
entry_slot_ang = 50;
entry_fin_ang  = entry_slot_ang - pitch_deg/2;   // 46.667° fin k's CCW face = feeder plate plane
// Nothing at the entry may reach inside r_seat_out (85.5): seated cards sweep that radius when the wheel turns.
nipE_r         = r_seat_out + 10.5;    // 96 entry nip roller axis (Ø16 rollers; nearest point r 88.3)
deck_tip_r     = nipE_r - 7.5;         // 88.5 the plate starts at the nip; the card bridges 11 mm to the fin tips
beamE_r        = 81.5;                 // "card in slot" beam: crosses the card plane obliquely between the towers
beamS_r        = 86.8;                 // "card seated" beam: blocked while a card still bridges plate and slot
beam_dz        = 4;                    // the oblique beams run from local z +4 (+Y tower) to -4 (-Y tower)
beamB_r        = nipE_r + 10.5;        // 106.5 gate beam
gate_r         = nipE_r + 22;          // 118 gate lip (inner face of gate wall); leaves room for the idler pivot
feed_r         = gate_r + 11.5;        // 129.5 feed roller axis (Ø27)
hop_len        = card_w + 1.5;         // 65 hopper interior along the radius
hop_w          = card_l + 2.1;         // 91 hopper interior across (Y)
hop_h          = 50;
wall           = 3;  plate_t = 3;
gate_gap_nom   = 0.45;  gate_win_h = 16;  gate_block_t = 3;
feed_roller_d  = 27;  feed_hub_d = 24;  oring_root_d = 20;  oring_cs = 3.5;
nip_roller_d   = 16;  nip_hub_d = 13;   nip_oring_root = 10;  nip_oring_cs = 3.0;
roller_len     = 64;  roller_stub = 8;   // short enough that the N20 motor fits inside the towers (|Y| < 58)
oring_y        = [-27, -10, 10, 27];
feed_protr     = 0.7;  nip_protr = 0.5;
n20_w = 12; n20_h = 10; n20_len = 24;
idler_d = 12; idler_w = 6; idler_y = [-27, 27];   // directly over the outer O-rings of the driven roller
rail_h = 6;
post_h = 23;            // idler pivot posts: top face, where the separate spring_bar screws on
spring_bar_y = 52;      // spring_bar screw positions (|Y|), in the middle of the 49..55 posts

// ---- exit (chute) ----------------------------------------------------------------
exit_slot_ang = 205;
exit_fin_ang  = exit_slot_ang + pitch_deg/2;    // 208.333° fin k+1; card lies on its CW face
nipX_r        = r_shroud_in + shroud_t + 1 + 8;  // 100.5 exit nip roller axis
beamX_r       = nipX_r + 10.5;                   // 111 exit beam (detector in the exit idler arm, like beam B)
chute_r0      = nipX_r + 9;                      // 109.5 chute floor starts
chute_len     = card_w + 9.5;                    // 73: the pile (against the end wall) starts 8 mm past beam X
chute_drop    = 28;                              // floor below the exit plane: a 54-card thick deck stays below the plane
chute_wall_h  = 4;                               // side walls only guide; low so the footprint stays under 12 in
chute_screw_x = nipX_r + 10.5;                   // 111: horizontal M3 x 20 screws through the tower cheeks into the nip housing
chute_screw_z = [-10, -22];                      //       (clear of the +Y motor pocket, which ends at x 106.7)

// ---- towers / frame --------------------------------------------------------------
tower_y_in    = 58;     // inner faces of the two towers
tower_t       = 12;
tower_x0      = -100; tower_x1 = 100;   // foot extent (plate fits a 220 mm bed; the chute passes beyond x -100)
tower_z_bot   = -100;   // base top (world Z of the wheel axis above the base = 100)
bearing_d     = 22.2;  bearing_t = 7;           // 608ZZ
nema_w = 42.3; nema_bolt = 31; nema_boss_d = 22.5; nema_len = 40;
coupler_d = 19; coupler_len = 25;
motor_standoff = 28;    // tower outer face → motor mounting face (coupler lives inside the standoff)
rod_len = 200;          // M8 threaded rod
servo_body = [22.8, 12.2, 22.5]; servo_flange = [32.5, 12.2, 2.5]; servo_hole_sp = 28;
hole_m3 = 2.6; hole_m3_free = 3.4; hole_m2 = 1.7; hole_m4_free = 4.4;
$fn = 64;

// ---- base ------------------------------------------------------------------------
base_x0 = -100; base_x1 = 133; base_hw = 105; base_h = 45;   // the chute end overhangs the rear base and clears the table by ~30 mm

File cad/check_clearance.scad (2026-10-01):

// check_clearance.scad — collision checks for the wheel shuffler (wheel frame, axis on Y, no base offset).
// Each `check` value renders the INTERSECTION of two volumes; an empty result means "no collision".
//   ./check_clearance.sh      (runs every check and reports OK / COLLISION)
use <shuffler.scad>
include <params.scad>

check = "list";

// ---- volumes swept by moving parts --------------------------------------------------------------
clear = 0.4;   // required clearance (mm)
module sweep_cards() { cyl_y(r_seat_out + clear, -46 - clear, 46 + clear); }                       // seated cards + cage play
module sweep_discs() { for (s=[-1,1]) translate([0, s > 0 ? 46 : -49 - clear, 0]) cyl_y(r_tip + clear, 0, 3 + clear); }
module sweep_tab()   { difference() { cyl_y(index_r1 + clear, 48.5, 53 + clear); cyl_y(index_r0 - clear, 48, 54); } }
module sweep_hub()   { for (s=[-1,1]) translate([0, s > 0 ? 49 : -55 - clear, 0]) cyl_y(hub_boss_r + clear, 0, 6 + clear); }
module sweep_all()   { sweep_cards(); sweep_discs(); sweep_tab(); sweep_hub(); }
// the hub and spacer turn with the wheel but must clear the towers' inner faces and the bearing (checked in sweep_towers via sweep_hub)

// ---- fixed parts in their assembled positions ---------------------------------------------------
module shutter_at(open=false) { rotate([0, open ? -shutter_open_deg : 0, 0]) shutter(); }
module feeder_parts() { at_fin(entry_fin_ang, 1) { feeder_deck(); gate_block(); feeder_motor_bracket(); feeder_bushing_bracket();
    idler_arm(nipE_r); spring_bar(nipE_r);
    translate([feed_r, -roller_len/2, 0.7 - 13.5]) rotate([-90,0,0]) roller_feed();
    translate([nipE_r, -roller_len/2, 0.5 - 8]) rotate([-90,0,0]) roller_nip(); } }
module feeder_motors() { at_fin(entry_fin_ang, 1) { for (p=[[feed_r, 0.7 - 13.5], [nipE_r, 0.5 - 8]]) translate([p[0] - 6, roller_len/2 + 0.5, p[1] - 5]) cube([12, 24, 10]); } }
module exit_parts() { at_fin(exit_fin_ang, -1) { chute(); idler_arm(nipX_r); spring_bar(nipX_r); translate([nipX_r, -roller_len/2, 0.5 - 8]) rotate([-90,0,0]) roller_nip(); } }
module exit_motor() { at_fin(exit_fin_ang, -1) translate([nipX_r - 6, roller_len/2 + 0.5, 0.5 - 8 - 5]) cube([12, 24, 10]); }
module towers() { tower(1); tower(-1); }
module wheel_extras() { cyl_y(hub_boss_r, -cage_w/2 - disc_t - hub_boss_len, -cage_w/2 - disc_t); }   // hub_spacer in place
module shrouds() { shroud_segment(shroud_a0, 270, true); shroud_segment(270, shroud_a1, false); }

module pair(a, b) { intersection() { children(0); children(1); } }

if (check == "sweep_feeder")   intersection() { sweep_all(); feeder_parts(); }
if (check == "sweep_motors")   intersection() { sweep_all(); union() { feeder_motors(); exit_motor(); } }
if (check == "sweep_exit")     intersection() { sweep_all(); exit_parts(); }
if (check == "sweep_towers")   intersection() { sweep_all(); towers(); }
if (check == "sweep_shroud")   intersection() { sweep_all(); shrouds(); }
if (check == "sweep_shutter_closed") intersection() { sweep_all(); shutter_at(false); }
if (check == "sweep_shutter_open")   intersection() { sweep_all(); shutter_at(true); }
if (check == "sweep_index")    intersection() { sweep_all(); index_bracket(); }
if (check == "motors_towers")  intersection() { union() { feeder_motors(); exit_motor(); } towers(); }
if (check == "brackets_towers") intersection() { at_fin(entry_fin_ang, 1) { feeder_motor_bracket(); feeder_bushing_bracket(); } towers(); }
if (check == "idler_deck")     intersection() { at_fin(entry_fin_ang, 1) idler_arm(nipE_r); at_fin(entry_fin_ang, 1) { feeder_deck(); gate_block(); spring_bar(nipE_r); } }
if (check == "idler_chute")    intersection() { at_fin(exit_fin_ang, -1) idler_arm(nipX_r); at_fin(exit_fin_ang, -1) { chute(); spring_bar(nipX_r); } }
if (check == "shutter_open_vs_fixed")   intersection() { shutter_at(true);  union() { exit_parts(); towers(); shrouds(); } }
if (check == "shutter_closed_vs_fixed") intersection() { shutter_at(false); union() { exit_parts(); towers(); shrouds(); } }
if (check == "shutter_mid_vs_fixed")    intersection() { rotate([0, -shutter_open_deg/2, 0]) shutter(); union() { exit_parts(); towers(); shrouds(); } }
if (check == "chute_shroud")   intersection() { at_fin(exit_fin_ang, -1) chute(); shrouds(); }
if (check == "deck_shroud")    intersection() { at_fin(entry_fin_ang, 1) feeder_deck(); shrouds(); }
if (check == "list") echo("set -D check=...");
// ---- mating parts that must touch only on their mounting faces (added in the print-readiness sweep)
if (check == "chute_towers")   intersection() { at_fin(exit_fin_ang, -1) chute(); towers(); }
if (check == "deck_towers")    intersection() { at_fin(entry_fin_ang, 1) { feeder_deck(); gate_block(); } towers(); }
if (check == "shroud_towers")  intersection() { shrouds(); towers(); }
if (check == "index_towers")   intersection() { index_bracket(); towers(); }
if (check == "motor_mount_tower") intersection() { motor_mount(); tower(1); }
if (check == "lid_deck")       intersection() { at_fin(entry_fin_ang, 1) lid(); at_fin(entry_fin_ang, 1) feeder_deck(); }

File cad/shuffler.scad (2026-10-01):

// shuffler.scad — WHEEL card shuffler: all printed parts + assembly.
//
//   openscad -D 'part="wheel"' -o stl/wheel.stl shuffler.scad
//   openscad -D 'part="assembly"' [-D explode=30] [-D section=1] -o png/... shuffler.scad
//
// Every "part=" selection is emitted in its print orientation resting on Z = 0.
// See params.scad for the frame and every dimension.
//
// Clearance rule used throughout: seated cards sweep every point with r <= r_seat_out (85.5) and
// |Y| <= 46 (card half-length + cage play) whenever the wheel turns, and the discs sweep r <= 77.5 at
// |Y| 46..49.  Nothing fixed may enter those volumes.

include <params.scad>

part = "assembly"; explode = 0; section = 0;

// ------------------------------------------------------------------ helpers
module box(p0, p1) { translate([min(p0[0],p1[0]), min(p0[1],p1[1]), min(p0[2],p1[2])])
    cube([abs(p1[0]-p0[0]), abs(p1[1]-p0[1]), abs(p1[2]-p0[2])]); }
module hole_z(x, y, d, z0, z1) { translate([x,y,z0]) cylinder(d=d, h=z1-z0); }
module hole_y(x, z, d, y0, y1) { translate([x,y0,z]) rotate([-90,0,0]) cylinder(d=d, h=y1-y0); }
module hole_x(y, z, d, x0, x1) { translate([x0,y,z]) rotate([0,90,0]) cylinder(d=d, h=x1-x0); }
// Fin-local frame at angle a: local X = radial outward, local Y = wheel axis,
// local Z = normal to the fin face on the card side (side=+1: CCW face, side=-1: CW face).
module at_fin(a, side=1) { rotate([0,-a,0]) mirror([0,0, side < 0 ? 1 : 0]) children(); }
module cyl_y(r, y0, y1) { translate([0,y0,0]) rotate([-90,0,0]) cylinder(r=r, h=y1-y0); }
module arc2d(r0, r1, a0, a1, n=48) { polygon(concat([for (i=[0:n]) let(a=a0+(a1-a0)*i/n) [r0*cos(a), r0*sin(a)]],
                                                  [for (i=[n:-1:0]) let(a=a0+(a1-a0)*i/n) [r1*cos(a), r1*sin(a)]])); }
// extrude a 2D shape drawn in the XZ plane (x right, z up) along Y from y0 to y1
module xz_extrude(y0, y1) { translate([0,y1,0]) rotate([90,0,0]) linear_extrude(y1-y0) children(); }
module arc_y(r0, r1, a0, a1, y0, y1) { xz_extrude(y0, y1) arc2d(r0, r1, a0, a1); }

// derived feeder / exit positions (local fin frames)
side_in = hop_w/2; side_out = side_in + wall;        // 45.5 / 48.5
feed_z  = feed_protr - feed_roller_d/2;              // -12.8
nip_z   = nip_protr - nip_roller_d/2;                // -7.5
piv_x0  = 8;  piv_x1 = 15.5;  piv_c = (piv_x0 + piv_x1)/2;   // idler pivot block, relative to the nip axis
mot_y0  = roller_len/2 + 0.5;                       // N20 gearbox face (motor body runs to mot_y0 + 24 < 58)
bush_y  = [-roller_len/2 - 10, -roller_len/2 - 2];  // stub-axle bushing block, -Y side

// ================================================================== WHEEL
module fin() {   // one fin in its local frame: CCW face on local Z = 0, body toward -Z
    difference() {
        box([r_hub - hub_wall + 0.5, -cage_w/2, -fin_t], [r_tip, cage_w/2, 0]);
        // lightening windows; pointed toward +Y (up when printed) so their tops print without bridging
        for (x=[[30, 47], [52, 71]], y=[[-38, -8], [8, 38]]) let(w = x[1] - x[0]) translate([0, 0, -fin_t - 1]) linear_extrude(fin_t + 2)
            polygon([[x[0], y[0]], [x[1], y[0]], [x[1], y[1] - w/2], [(x[0] + x[1])/2, y[1]], [x[0], y[1] - w/2]]);
        // lead-in: both faces chamfered over the last 2.5 mm so an incoming card rides onto the fin
        xz_extrude(-cage_w/2 - 1, cage_w/2 + 1) polygon([[r_tip - 2.5, 0.01], [r_tip + 0.1, 0.01], [r_tip + 0.1, -fin_t/2]]);
        xz_extrude(-cage_w/2 - 1, cage_w/2 + 1) polygon([[r_tip - 2.5, -fin_t - 0.01], [r_tip + 0.1, -fin_t - 0.01], [r_tip + 0.1, -fin_t/2]]);
    }
}
module disc(y0, y1, with_tab=false, solid=false) {   // solid: the -Y disc, which is the first layers on the bed
    difference() {
        union() {
            if (solid) cyl_y(r_tip, y0, y1);
            else {
                arc_y(disc_ring_in, r_tip, 0, 360, y0, y1);
                cyl_y(hub_boss_r, y0, y1);
                for (i=[0:n_spokes-1]) rotate([0, -i*360/n_spokes, 0]) box([0, y0, -4], [r_tip - 2, y1, 4]);
            }
            if (with_tab) arc_y(index_r0, index_r1, index_ang - 3, index_ang + 3, y0, y1 + index_w);   // tab inside the rim
        }
        cyl_y(bore_d/2, y0 - 1, y1 + index_w + 1);
    }
}
module wheel() {
    difference() {
        union() {
            difference() { cyl_y(r_hub, -cage_w/2, cage_w/2); cyl_y(r_hub - hub_wall, -cage_w/2 - 1, cage_w/2 + 1); }   // hub tube
            cyl_y(7, -cage_w/2, cage_w/2);                                                         // bore tube and ribs inside the hub:
            for (i=[0:5]) rotate([0, -(30 + i*60), 0]) box([5, -cage_w/2, -0.8], [r_hub - hub_wall + 0.5, cage_w/2, 0.8]);   // the +Y disc bridges between them
            for (k=[0:n_slots-1]) rotate([0, -k*pitch_deg, 0]) fin();
            disc(-cage_w/2 - disc_t, -cage_w/2, solid=true);
            disc(cage_w/2, cage_w/2 + disc_t, true);
            cyl_y(hub_boss_r, cage_w/2, cage_w/2 + disc_t + hub_boss_len);        // +Y hub boss (the -Y one is the separate hub_spacer)
        }
        cyl_y(bore_d/2, -100, 100);
    }
}

// Spacer between the -Y disc and its clamp nut (a separate part so the wheel prints with its flat disc on the bed).
module hub_spacer() { difference() { cylinder(r=hub_boss_r, h=hub_boss_len); translate([0,0,-1]) cylinder(d=bore_d, h=hub_boss_len + 2); } }

// ================================================================== SHROUD + SHUTTER
// The arc runs from tower to tower (|Y| <= ye) so it prints standing on a full edge (+Y down).  Beyond |Y| 46 it is
// outside every moving part except on the -Y side over the shutter drive tab's travel, where that skirt is left off;
// across the window the +Y skirt is a strap that ties the two sides of the window together.
module shroud_segment(a0, a1, window=false) {
    ye = tower_y_in;
    ri = r_shroud_in; ro = r_shroud_in + shroud_t;
    difference() {
        union() {
            arc_y(ri, ro, a0, a1, -shroud_w/2, ye);
            if (window) { arc_y(ri, ro, a0, win_a0 - 1, -ye, -shroud_w/2 + 0.01); arc_y(ri, ro, shut_skirt_a1, a1, -ye, -shroud_w/2 + 0.01); }
            else arc_y(ri, ro, a0, a1, -ye, -shroud_w/2 + 0.01);
            for (a=[a0 + 4, a1 - 4], s=[-1,1]) rotate([0,-a,0]) hull() {                                                       // tabs to the towers,
                box([ri, s*(shroud_w/2 - 9), -6], [ro, s*tower_y_in, 6]); box([ri, s*(shroud_w/2 - 2), -6], [ri + 10, s*tower_y_in, 6]); }   // 45° underneath
        }
        if (window) arc_y(ri - 1, ro + 1, win_a0, win_a1, -shroud_w/2 - 1, shroud_w/2 + 1);
        for (a=[a0 + 4, a1 - 4], s=[-1,1]) rotate([0,-a,0]) hole_y(r_shroud_in + 5, 0, hole_m3_free, s*(tower_y_in - 8), s*(tower_y_in + 1));
    }
}
// Blade profile (XZ): outer radius constant, inner radius ramps from 87.8 at the tips to 87.0.
function shut_rin(a) = a < shut_a0 + shut_ramp ? 87.8 - 0.8*(a - shut_a0)/shut_ramp
                     : a > shut_a1 - shut_ramp ? 87.0 + 0.8*(a - (shut_a1 - shut_ramp))/shut_ramp : shut_r_in;
module shutter() {   // closed position; the servo slides it shutter_open_deg counter-clockwise to open
    n = 60;
    difference() {
        union() {
            xz_extrude(-shut_hw, shut_hw) polygon(concat(
                [for (i=[0:n]) let(a = shut_a0 + (shut_a1 - shut_a0)*i/n) [shut_r_out*cos(a), shut_r_out*sin(a)]],
                [for (i=[n:-1:0]) let(a = shut_a0 + (shut_a1 - shut_a0)*i/n) [shut_rin(a)*cos(a), shut_rin(a)*sin(a)]]));
            arc_y(shut_tab_r0, shut_tab_r1, shut_tab_a - 3, shut_tab_a + 3, -shut_hw, -shroud_w/2 - 0.5);   // drive tab beside the shroud end
        }
        // radial pin slot: the horn pin moves between r = shut_pin_r (ends of travel) and servo_ax_r + horn_r (mid travel)
        rotate([0, -shut_tab_a, 0]) hull() for (r=[shut_pin_r - 0.6, servo_ax_r + horn_r + 0.6]) hole_y(r, 0, 2.4, -shut_hw - 1, -shroud_w/2);
    }
}
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

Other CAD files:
cad/stl/roller_nip.stl
cad/stl/base_cover_front.stl
cad/stl/index_bracket.stl
cad/stl/gate_block.stl
archive/v1-elevator-insertion/cad/params.scad
archive/v1-elevator-insertion/cad/shuffler.scad
archive/v1-elevator-insertion/cad/stl/bushing_bracket.stl
archive/v1-elevator-insertion/cad/stl/carriage.stl
archive/v1-elevator-insertion/cad/stl/column.stl
archive/v1-elevator-insertion/cad/stl/feeder_deck.stl
archive/v1-elevator-insertion/cad/stl/gate_block.stl
archive/v1-elevator-insertion/cad/stl/idler_arm.stl
archive/v1-elevator-insertion/cad/stl/idler_wheel.stl
archive/v1-elevator-insertion/cad/stl/knife_bar_lower.stl
archive/v1-elevator-insertion/cad/stl/knife_bar_upper.stl
archive/v1-elevator-insertion/cad/stl/lid.stl
archive/v1-elevator-insertion/cad/stl/motor_bracket.stl
archive/v1-elevator-insertion/cad/stl/motor_retainer.stl
archive/v1-elevator-insertion/cad/stl/platform.stl
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

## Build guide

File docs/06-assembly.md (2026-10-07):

# 6. Assembly instructions

The build order lets you test the feeder on the bench first, then the wheel,
then everything else (`09-prototype-plan.md`). Part names refer to
`cad/stl/`, dimensions to `cad/params.scad`, and views to `cad/png/` and
`docs/img/`.

## 6.1 Tools

* **Required:** 3D printer (0.4 mm nozzle), calipers, feeler gauge set,
  hex and Phillips drivers (M3, M2), pliers, side cutters, soldering iron,
  JST-XH crimper or pre-crimped leads, files and 600-grit paper, hacksaw
  (for the M8 rod), multimeter, USB cable.
* **Optional:** M3 tap, 8 mm drill for reaming, heat-set insert tip.

## 6.2 Fasteners

| Use | Fastener | Qty |
|---|---|---|
| Brackets to the deck, shroud tabs, base covers, index bracket | M3 × 8 self-tapping (2.6 mm holes) | ≈ 40 |
| Tower feet to base | M3 × 10 | 12 |
| Feeder deck to the tower arms (down through the plate into the arms) | M3 × 12 | 4 |
| Chute to the tower cheeks (horizontal, from the towers' outer faces) | M3 × 20 | 4 |
| NEMA 17, through the +Y tower and the motor_mount | M3 × 40 | 4 |
| Spring bars to the idler pivot posts | M3 × 10 | 4 |
| Gate clamp | M3 × 12 | 2 |
| Idler axles | M3 × 50 + nyloc | 2 |
| Idler pivots | M3 × 10 | 4 |
| Bushing cross screws | M3 × 20 | 3 |
| Lid hinge | M3 × 60 (or 3 mm rod) | 1 |
| Roller set screws | M3 × 5 grub | 3 |
| Wheel on the rod | M8 nyloc nuts + washers | 4 + 6 |
| Servo flange | M2 × 8 | 2 |
| Shutter drive pin (through the horn) | M2 × 12 | 1 |

## 6.3 Stage A: feeder module (steps 1–12)

1. **Prepare the feeder deck.** Cut the three thin print ribs out of the
   gate window with flush cutters and file the window edges flat. Run an
   M3 screw through every 2.6 mm hole. Sand the hopper floor and the plate
   between the gate and the nip.
2. **Gate block.** Round the lip (the lower edge on the hopper side) to R1
   with 600-grit. Fit the block into the window from the wheel side. Put two
   M3 × 12 screws through the slots into the bosses, finger-tight.
3. **Rollers.** Fit 4 O-rings 20 × 3.5 on `roller_feed` and 4 O-rings
   10 × 3 on each `roller_nip`. Put a grub screw in each D-bore end.
4. **Bushing bracket (−Y side).** Drop the feed roller's and entry nip's
   stub axles into the U-slots, then close each with its M3 × 20.
5. **Motor bracket (+Y side).**
   1. Push the two N20 motors up into the pockets from below, shafts
      toward the rollers. The pockets are a push fit, so add a dab of hot
      glue.
   2. Hold both brackets under the plate so the shafts enter the rollers'
      D-bores.
   3. Screw each bracket to the plate's underside with 2 × M3 × 8.
   4. Tighten the roller grub screws onto the flats.
6. **Check** that the rollers turn freely and their crowns sit 0.7 mm
   (feed) and 0.5 mm (nip) above the plate.
7. **Beam B emitter.** Push a 3 mm IR LED into the pocket at r 106.5 from
   below, dome up against the aperture, and hot-glue it.
8. **Entry idler arm.**
   1. Fit O-rings on two `idler_wheel`s, then fit the wheels on an
      M3 × 50 axle with a nyloc. They sit over the roller's outer O-rings.
   2. Push the beam-B phototransistor into the arm's boss from above,
      leads up.
   3. Mount the arm on the pivot posts (2 × M3 × 10). It must pivot
      freely.
   4. Drop a pen spring into each spring pocket. Thread the
      phototransistor leads up through the hole in a `spring_bar`, then
      screw the bar across the tops of the pivot posts (2 × M3 × 10). The
      springs bear on it.
9. **Gate.** Put a 0.45 mm feeler under the block, press the block down
   and tighten. Check that 0.40 passes and 0.55 does not.
10. **Lid.** Fit the hinge with the M3 × 60. Put a felt pad under the boss.
    Drop two dead AA cells into the pockets in the top of the lid and tape
    over them.
11. **Bench test (Stage 1).** Put the electronics on a breadboard (§6.6).
    Clamp the deck at 50° with a box below the nip. Run `feed` 100 times
    with a deck loaded, tuning `cal pwm feed`, `cal pwm nipe` and the gate
    until 100 consecutive single feeds succeed. Beams E and S are on the
    towers, so on the bench `feed` reports a jam after beam B. Beam B's
    timing is what you are tuning here.
12. Hot-glue the beam leads to the plate's underside.

## 6.4 Stage B: wheel module (steps 13–24)

13. **Wheel.** Clean the slot mouths with a 1.5 mm feeler blade run down
    each slot. A card must slide to the hub and back out freely in all 54
    slots. Ream the bore to 8.6 mm if the rod does not pass.
14. **Rod.**
    1. Cut the M8 rod to 165 mm and deburr it.
    2. Put a washer and nyloc on one end, 8 mm in.
    3. Slide the `hub_spacer` onto the rod, then the wheel with its plain
       (−Y) disc against the spacer. Add a washer and nyloc on the other
       side.
    4. Clamp the wheel centred, with the index-tab disc toward the long end
       of the rod.
    5. Wrap one layer of tape on the thread where each bearing will sit.
15. **Towers.**
    1. Press a 608ZZ into each bearing pocket.
    2. Fit the beam E and beam S parts into the 4 mm bosses on the towers'
       inner faces: IR LEDs in the +Y tower, phototransistors in the −Y
       tower. Leads go out through the holes to the outer face. Hot-glue
       them.
    3. Fit the index LED and phototransistor in `index_bracket`, facing
       each other across the gap, and screw the bracket to the post on the
       +Y tower (2 × M3 × 8).
    4. **Motor, before the wheel goes in** (the bolts go in from the
       tower's inner face, which the wheel later covers). Fit the coupler
       on the NEMA 17 shaft. Hold `motor_mount` on the +Y tower's outer
       face and the motor on the mount. Push 4 × M3 × 40 from the inner
       face (heads into the counterbores) through the tower and the mount
       into the motor, and tighten them evenly.
16. **Shroud and shutter.** Lay the `shutter` blade inside `shroud_A`
    against the window, with its drive tab at the −Y end beside the shroud.
    It must slide 17.5° freely. Sand its outer face if it drags.
17. **Base.** Join `base_front` and `base_rear` on a flat surface. Screw
    the −Y tower's foot down (6 × M3 × 10). Stand the +Y tower loosely.
18. **Wheel into the towers.** Slide the rod through the −Y bearing (short
    end first). Bring the +Y tower, with its motor, onto the long end so
    the rod passes through the bearing into the coupler, and screw its foot
    down. The wheel must spin freely with axial play under 0.5 mm.
19. **Shroud segments.** Fit both segments between the towers (two tabs
    each end, M3 × 8). Load a few cards by hand at 12 o'clock and rotate
    them through the bottom. They should ride on the shroud and on the
    shutter's ramps without catching.
20. **Coupler.** Turn the wheel by hand to check the rod is centred in the
    coupler, then tighten the coupler's rod-side screws through the
    `motor_mount` access windows.
21. **Shutter servo.** Centre the MG90S at 1500 µs. Drop it into the
    −Y tower's pocket from the outside, flange on the outer face, and
    secure it with 2 × M2 × 8. Fit a single-arm horn inside the recess,
    pointing at mid-travel. Screw an M2 × 12 through the horn's hole at
    r ≈ 18 into the shutter tab's slot. Then set `cal shutter closed` (blade
    centred on the window) and `cal shutter open` (window clear).
22. **Bench test (Stage 2).** Run `home`, then `entry 0`. Check with a
    straight edge that fin 0's upper face lies 0.3° (0.4 mm at the tip)
    below where the feeder plate will sit, and adjust `cal home`. Run
    `entry 10` and `entry 40`: the wheel goes the short way. Run `scan` with
    a few cards placed by hand: the reported slots must match.
23. **Feeder on the wheel.** Screw the feeder deck to the tower arms
    (4 × M3 × 12, down through the plate into the arms). Push a card by hand through
    the nip into the slot at the entry. It must slide down to the hub, with
    beam E blocked and beam S clear (`beams`). Fine-tune `cal entry`
    (±0.1°) until cards enter cleanly in slots 0, 13, 27 and 40.
24. **Feed test.** Load 20 cards with `feed`, indexing the wheel with
    `entry k` each time, then run `scan`: 20 occupied, all at the intended
    slots.

## 6.5 Stage C: exit module (steps 25–29)

25. **Chute.**
    1. Fit the exit `roller_nip` with O-rings: stub in the −Y U-slot,
       closed with an M3 × 20 cross screw.
    2. Push the N20 into the +Y pocket and hot-glue it.
    3. Put the beam X LED into the floor pocket from below.
    4. Fit the second `idler_arm` (its boss takes the beam X
       phototransistor) with wheels and springs, then its `spring_bar`
       (2 × M3 × 10), as in step 8.
26. **Felt.** Stick a felt strip on the inside face of the chute end wall.
27. **Mount.** Slide the chute in between the towers from outside (it
    clears each tower face by 0.5 mm) and screw it to the tower cheeks:
    4 × M3 × 20, horizontal, from the towers' outer faces into the nip
    housing.
28. **Bench test (Stage 3).** With cards in the wheel, run `exit 5`,
    then `shutter open`, then `eject`. The card slides out and is
    pulled through, beam X blocks then clears, and the card lands in the
    chute. Adjust `cal exit` and `cal pwm nipx`. Repeat for slots 0, 27
    and 53, with `shutter close` before each `exit k`. Never turn the
    wheel with the shutter open: the cards over the window slide out
    and the move drags them across its edge.
29. **Full shuffle.** Run `test fixed 1` and press the button. Compare the
    result with `analyze_physical.py --compare`.

## 6.6 Stage D: electronics (steps 30–37)

30. **Perfboard.** Build it to `electronics/wiring-diagram.svg`:
    * ESP32, TMC2208 and two DRV8833 on female headers, plus the buck
      module;
    * NPN with a 470 Ω base resistor;
    * LED resistors: 150 Ω for B and X, 68 Ω for E and S, 330 Ω for the
      index LED, which is always on;
    * five 10 kΩ pull-downs;
    * 100 kΩ/33 kΩ divider with 100 nF;
    * capacitors: 100 µF × 3 and 470 µF;
    * JST-XH headers J1–J17.
31. **Set the voltages.** Set the buck to 5.00 V with nothing connected.
    Set the TMC2208 Vref to ≈ 1.4 V (≈ 1.0 A RMS on 0.11 Ω-sense modules)
    with the motor unplugged. Tie MS1 and MS2 to 3V3.
32. **Harness.** Make leads for:
    * stepper (4-pin) and three N20 motors (2-pin each);
    * servo (3-pin);
    * beams B, E, S and X (4-pin each);
    * index (4-pin);
    * button, pixel and buzzer.

    Label every lead.
33. **Battery.** Put the fuse in the positive lead, then the switch, then
    the VBAT input. Wire the charge jack across the pack's protected
    terminals. Velcro the pack in the front base box on a foam pad.
34. **Flash.** Flash the firmware with the battery disconnected (USB
    power).
35. **First power-up** on battery, motor connectors unplugged. Run `bat`,
    then `cal vbat <meter>`, then `beams`, then `cal beams`.
36. **Connect the rest.** Plug in the sensors, servo and N20s. Power off
    before plugging in the stepper.
37. **Finish.** Route cables along the towers and close the base covers.

## 6.7 Calibration (first use)

| Step | Command | Target |
|---|---|---|
| C1 | `cal vbat 12.30` (your meter reading) | battery gain |
| C2 | `cal beams` (machine empty) | thresholds; "WEAK" means realign that pair |
| C3 | `home` | index found |
| C4 | `entry 0` with a straight edge, then `cal home <deg>` | fin 0 face 0.4 mm below the plate plane at its tip |
| C5 | `cal shutter closed` / `cal shutter open` | blade over the window / window clear |
| C6 | deck in the hopper; `feed` ×20 with `entry k` | 20 × "ok", no double-feed suspects |
| C7 | `cal entry ±0.1` if cards stop in the mouth or land in a neighbour | beam E blocked and beam S clear after every feed |
| C8 | cards in the wheel; `exit k`; `shutter open`; `eject`; `shutter close` | pulled out cleanly; adjust `cal exit` |
| C9 | `test fixed 1`, then press the button | `last` shows 0 corrections; compare the deck |

## 6.8 First-use checks

* The wheel never moves while beam S or beam X is blocked. Push a card
  halfway into the mouth and try `jog 10`: it must be refused.
* No card is visible outside the shroud during loading.
* Every card lands flat in the chute and slides to the end wall.
* The stepper is warm, not hot, after 10 shuffles at 1 A.
* `last` shows zero corrections, retries and double-card suspects for a
  good deck.
* The battery drops less than 0.1 V over 5 shuffles.

## 6.9 Adjustments

| Symptom | Adjust |
|---|---|
| Two cards fed together | gate −0.05; less lid ballast; smooth the lip |
| Card not picked | gate +0.05; more ballast; clean the O-rings; raise `cal pwm feed` |
| Card stops in the mouth (ERROR 3, "stuck in the slot mouth") | `cal entry` −0.1 (fin lower); polish the fin lead-ins; raise `cal pwm nipe` |
| Corrections logged, all in one direction | `cal entry` by ±0.1° in that direction |
| Card does not slide out at the exit | `cal exit`; check the shutter opens fully; wipe the shroud |
| Eject jams | `cal pwm nipx`; idler springs |
| Index not found | index LED and phototransistor alignment; `cal home` |
| Stepper skips on long moves | Vref up to 1.6 V (1.1 A); lower `WHEEL_ACC_DPS2` to 3500 |

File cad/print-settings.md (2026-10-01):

# Print list and settings

Every STL in `stl/` is exported in its print orientation, resting on Z = 0:
load it, do not rotate it, do not add supports. Regenerate with
`./render.sh stl` after editing `params.scad` / `shuffler.scad`, then run
`python3 check_printability.py` (mesh, floating pieces, bed size and
support-free overhangs, slice by slice) and `./check_clearance.sh`.

**24 files, 30 pieces.** Printer: 0.4 mm nozzle, bed ≥ 220 × 220 mm (the
towers are 213 × 198 mm).

| # | File | Qty | Material | Layer | Infill | Size (mm) | Notes |
|---|---|---|---|---|---|---|---|
| 1 | wheel | 1 | PETG | 0.2 | 30 % | 155 × 155 × 104 | solid disc on the bed; ≈ 24 h, ≈ 375 g (the 54 fins print solid). Print it first and test it (below) |
| 2 | hub_spacer | 1 | PETG | 0.2 | 40 % | Ø30 × 6 | goes on the rod between the −Y disc and its nut |
| 3 | tower_R | 1 | PETG | 0.2 | 40 % | 213 × 198 × 16 | outer face down. Skirt off or ≤ 3 mm (it nearly fills a 220 bed) |
| 4 | tower_L | 1 | PETG | 0.2 | 40 % | 213 × 198 × 16 | as tower_R |
| 5 | motor_mount | 1 | PETG | 0.2 | 40 % | Ø50 × 28 | tower face down |
| 6 | shroud_A | 1 | PETG | 0.2 | 30 % | 99 × 112 × 116 | standing on its +Y edge; 5 mm brim (tall and thin) |
| 7 | shroud_B | 1 | PETG | 0.2 | 30 % | 99 × 112 × 116 | as shroud_A |
| 8 | shutter | 1 | PETG | 0.2 | 100 % | 17 × 25 × 97 | standing on its end; 5 mm brim; sand the outer face smooth |
| 9 | index_bracket | 1 | PETG | 0.2 | 40 % | 24 × 36 × 8 | back plate down |
| 10 | feeder_deck | 1 | PETG | 0.2 | 25 % | 106 × 142 × 61 | plate down. Has 3 thin ribs in the gate window: **cut them off** after printing |
| 11 | gate_block | 1 | PETG | 0.15 | 50 % | 16 × 107 × 6 | flange down |
| 12 | roller_feed | 1 | PLA | 0.15 | 30 % | Ø24 × 72 | D-bore end down, stub axle up |
| 13 | roller_nip | **2** | PLA | 0.15 | 30 % | Ø13 × 72 | as roller_feed. One for the entry nip, one for the exit nip |
| 14 | feeder_motor_bracket | 1 | PETG | 0.2 | 30 % | 56 × 28 × 19 | motor pockets open at the bed |
| 15 | feeder_bushing_bracket | 1 | PETG | 0.2 | 30 % | 58 × 8 × 19 | |
| 16 | idler_arm | **2** | PETG | 0.2 | 30 % | 24 × 95 × 16 | upside down. Entry and exit use the same part |
| 17 | idler_wheel | **4** | PLA | 0.15 | 50 % | Ø12 × 6 | two per idler arm; print 1–2 spares |
| 18 | spring_bar | **2** | PETG | 0.2 | 40 % | 16 × 110 × 4 | one per idler arm; screws onto the pivot posts |
| 19 | lid | 1 | PLA | 0.2 | 20 % | 83 × 97 × 62 | top face down, pressure boss up |
| 20 | chute | 1 | PETG | 0.2 | 25 % | 90 × 115 × 54 | floor down |
| 21 | base_front | 1 | PLA | 0.28 | 15 % | 193 × 210 × 45 | top face down (open side up) |
| 22 | base_rear | 1 | PLA | 0.28 | 15 % | 40 × 210 × 45 | as base_front |
| 23 | base_cover_front | 1 | PLA | 0.2 | 20 % | 186 × 203 × 2.5 | |
| 24 | base_cover_rear | 1 | PLA | 0.2 | 20 % | 33 × 203 × 2.5 | |

Only the feed roller drives without an idler: the hopper's weight and the
lid press the bottom card onto it. The two nips (entry and exit) each have
one `roller_nip` below the card and one `idler_arm` with two
`idler_wheel`s above it.

**All parts:** 3 perimeters, 4 top / 4 bottom layers, no supports. PETG
for everything that touches cards or carries load; PLA is fine for the
rollers (they carry O-rings), idler wheels, lid and base.

**Filament [EST]:** ≈ 0.9 kg PETG + ≈ 0.35 kg PLA (≈ 1.25 kg in total).
The wheel alone is ≈ 375 g. One 1 kg PETG spool is just enough if nothing
fails; buy a second if the wheel might need a reprint.

## Suggested order

1. **wheel**, then check it before printing anything else: slide a real
   card into all 54 slots. It must drop to the hub and come back out
   freely. If cards stick, widen the slots (`fin_t` in `params.scad`) and
   reprint before going on.
2. tower_R, tower_L, motor_mount, hub_spacer, shroud_A, shroud_B, shutter,
   index_bracket. Check the wheel turns freely on its rod inside the
   towers and shrouds (assembly Stage B).
3. feeder_deck, gate_block, rollers, brackets, idler arms and wheels,
   spring bars, lid, chute.
4. base parts last: they do not affect function.

## After printing

* **feeder_deck:** cut the three 1.2 mm ribs out of the gate window with
  flush cutters and file the window edges flat. The gate block must slide
  in without binding. Check the plate tip (the edge facing the wheel) is
  flat.
* **wheel:** run a 1.5 mm feeler blade down every slot. Ream the bore to
  8.6 mm if the rod does not pass.
* **towers:** press-fit test a 608 bearing; ream or sand the pocket if it
  is too tight.
* **every 2.6 mm hole:** run an M3 screw through it once (they are tapped
  by the screw).
* **shutter:** deburr the edges and sand the outer face; it slides on the
  shroud's inner face.
* **gate_block:** round the hopper-side lower edge (the lip) to R1 with
  600-grit.
* **rollers:** check the stub axle is straight. Reprint if it bent while
  printing (slow down or add a cooling pause for the last 8 mm).

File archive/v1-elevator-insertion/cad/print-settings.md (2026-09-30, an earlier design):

# Print settings and orientation

Every STL in `stl/` is already in its print orientation and rests on Z = 0.
Regenerate with `./render.sh stl` after editing `params.scad` / `shuffler.scad`.

| Part | Qty | Material | Layer | Infill | Supports | Notes |
|---|---|---|---|---|---|---|
| feeder_deck | 1 | PETG (PLA ok) | 0.2 | 25 % | none | brim; plate on the bed, walls up |
| well_deck | 1 | PETG | 0.2 | 25 % | none | brim; guide loops bridge 22 mm — fine at 0.2 mm |
| well_sleeve | 1 | PETG | 0.2 | 25 % | none | |
| column | 1 | PETG | 0.2 | 40 % | top plate only (66 mm bridge) or accept a sagging bridge and drill the holes | 119 mm tall; brim |
| carriage | 1 | PETG | 0.2 | 40 % | none | prints on its rear face |
| platform | 1 | PLA | 0.2 | 30 % | none | sand the top face smooth |
| roller | 2 | PLA | 0.15 | 30 % | none | axis vertical; clean the O-ring grooves |
| gate_block | 1 | PETG | 0.15 | 50 % | none | round the lip with 600-grit |
| knife_bar_lower / upper | 2 + 2 | PETG | 0.15 | 50 % | none | flat; the mating faces are the bed faces |
| servo_bracket | 2 | PETG | 0.2 | 30 % | none | |
| motor_bracket, bushing_bracket | 1 + 1 | PETG | 0.2 | 30 % | none | |
| motor_retainer | 2 | any | 0.2 | 50 % | none | |
| idler_arm | 1 | PETG | 0.2 | 30 % | none | printed upside down |
| idler_wheel | 2 | PLA | 0.15 | 50 % | none | |
| lid | 1 | PLA | 0.2 | 20 % | none | printed upside down; AA troughs bridge 15 mm |
| skirt_front, skirt_rear | 1 + 1 | PLA | 0.2–0.28 | 15 % | none | 2 perimeters are enough; brim |

Nozzle 0.4 mm, 3 perimeters unless noted, 4 top/bottom layers. Total ≈ 650 g.

Post-processing: ream the 8.15 mm rod holes in the column with an 8 mm rod;
run an M3 tap or a screw through every 2.6 mm hole once before assembly;
deburr the blade slots in the well side walls with a 1 mm feeler blade.

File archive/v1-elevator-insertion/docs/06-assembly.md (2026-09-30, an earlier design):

# 6. Assembly instructions

Build order is chosen so that the feeder can be tested on its own before the
well module exists (see `09-prototype-plan.md`). Part names refer to
`cad/stl/`; dimensions to `cad/params.scad`; views to `cad/png/` and
`docs/img/`.

## 6.1 Tools

* 3D printer (0.4 mm nozzle), calipers, feeler gauge set (0.30–0.60 mm)
* Hex/Phillips drivers for M3 and M2, small needle-nose pliers, side cutters
* Soldering iron, wire strippers, JST-XH crimper (or pre-crimped leads)
* Files (flat, needle), 400/600-grit paper, tin snips or a hacksaw for brass
* Multimeter, USB cable for the ESP32
* Optional: M3 tap, 8 mm reamer or a spare 8 mm rod, heat-set insert tip

## 6.2 Fasteners

| Use | Fastener | Qty |
|---|---|---|
| Brackets, sleeve, servo brackets, column flange, bar halves, platform | M3 × 8 self-tapping into 2.6 mm holes | ≈ 36 |
| Gate clamp | M3 × 12 | 2 |
| Deck-to-deck flange | M3 × 12 + nut | 4 |
| Column flange | M3 × 10 + nut | 4 |
| NEMA 17 | M3 × 8 (through the 4 mm top plate) | 4 |
| T8 nut | M3 × 8 | 4 |
| Rod grub screws | M3 × 6 grub (or M3 × 8) | 4 |
| Idler axle | M3 × 50 + nyloc | 1 |
| Idler pivot | M3 × 10 | 2 |
| Bushing bracket cross screws | M3 × 20 | 2 |
| Lid hinge | M3 × 60 (or 3 mm rod 70 mm) | 1 |
| Roller set screws | M3 × 5 grub | 2 |
| Skirt mounting | M3 × 10 | 8 |
| Servo tabs, endstop | M2 × 8 | 6 |

## 6.3 Stage A — feeder module (steps 1–13)

1. **Post-process the feeder deck.** Run an M3 screw through every 2.6 mm
   hole. Sand the hopper floor and the guide plate between gate and flange
   smooth (cards slide on them). Check the gate window is clear.
2. **Gate block.** Round the lower inner edge of the gate block with 600-grit
   until it is a smooth R1 radius (this edge touches the second card).
   Fit it into the window from the outside, insert the two M3 × 12 clamp
   screws through the slots into the bosses, finger-tight.
3. **Rollers.** Fit three O-rings (ID 20 × 3.5) into each roller's grooves.
   Screw an M3 × 5 grub screw into the radial hole of the D-bore end so its
   tip is just below the bore. Check the stub axle is straight.
4. **Bushing bracket (−Y side).** Drop the two rollers' stub axles into the
   U-slots, then close each U with its M3 × 20 cross screw (the screw passes
   under the axle). Do not tighten the bracket to the deck yet.
5. **Motor bracket (+Y side).** Slide each N20 motor into its pocket from
   the outside with the shaft toward the rollers, wires outward. Hold the
   bracket against the plate's underside so the shafts enter the rollers'
   D-bores (rotate the rollers to align the flats), then screw both brackets
   to the plate's underside (4 × M3 × 8 each). Tighten the roller grub
   screws onto the shaft flats. Fit the motor retainer plates (2 × M3 × 8
   each).
6. **Check:** each roller turns freely by hand with the motor's gearbox
   resistance only, no wobble > 0.3 mm at the crown, crowns protrude
   0.7 (feed) and 0.5 mm (transport) above the plate — measure with a
   straight edge and feeler gauge across the slot.
7. **Beam B emitter.** Push a 3 mm IR LED into the vertical pocket at
   X = 19 from below (anode/cathode leads down), dome up, until it seats
   against the 2 mm aperture. Secure with a drop of hot glue on the leads
   under the plate. Solder 150 mm leads.
8. **Idler arm.** Fit an O-ring (9 × 2) on each idler wheel. Place the
   wheels in the forks with the M3 × 50 axle through the arm and wheels,
   nyloc on the end. Push the 3 mm phototransistor into the sensor boss from
   above (leads up), seating on the 2 mm aperture; hot-glue the leads.
   Mount the arm on the pivot blocks with 2 × M3 × 10 (arm must pivot
   freely). Drop a pen spring into each spring pocket; the springs bear
   against the underside of the lid bridge (added in step 12) — for now the
   arm rests by its own weight.
9. **Gate setting.** Loosen the clamp screws, lay a 0.45 mm feeler blade
   on the floor under the gate, press the block down onto it, tighten,
   remove the blade. Check with 0.40 (passes) and 0.55 (does not pass).
10. **Hinge and lid.** Line up the lid's two knuckles between the deck's
    three, push the M3 × 60 through (or a 3 mm rod). Stick a felt pad
    (30 × 50 mm) under the lid's boss. Put two dead AA cells in the troughs
    and tape them.
11. **Skirt (front).** Install the panel parts in the front skirt: start
    button (12 mm hole), status LED (6 mm), power switch (6.5 mm), charge
    jack (8.5 mm). Do not mount the deck on the skirt yet — the feeder is
    tested on the bench first.
12. **Idler spring bridge.** With the lid closed, the lid bridge sits over
    the idler arm; the springs should be compressed ~3 mm. If not, add a
    washer under each spring.
13. **Bench test of the feeder** (Stage 1 of the prototype plan): with the
    electronics on a breadboard (§6.5), run `feed` from the serial console
    with a deck loaded and a box catching the cards. Tune `cal pwm feed`,
    `cal pwm trans` and the gate until 100 consecutive single feeds succeed.

## 6.4 Stage B — well module (steps 14–27)

14. **Blades.** Cut two 40 × 22 mm pieces of 0.5 mm brass. File a symmetric
    bevel ≈ 1.5 mm long on both faces of one 40 mm edge (the entry edge),
    round the two corners R1, polish the bevel and both faces to 600 grit.
    Drill/punch two 3.2 mm holes 17.5 mm from the entry edge, 30 mm apart
    (the bar halves are the template: clamp a half to the brass and mark).
    Wipe with alcohol.
15. **Bars.** Lay a blade on a lower bar half with the entry edge toward
    the well side (the side with the pin slot away from you), 10.5 mm of
    blade overhanging the bar's inner face, screw the upper half on
    (2 × M3 × 10). Repeat for the second side (mirror). Check: blade flat,
    no rock, overhang 10.5 ± 0.3 mm on both.
16. **Well deck.** Deburr the two blade slots with a 1 mm feeler blade.
    Ream the beam-S apertures with a 1.6 mm drill. Slide each bar through
    its two guide loops from the outside; it must slide 8 mm freely and the
    blade tip must stop 1 mm inside the wall's inner face when the bar is
    fully out (adjust by loosening the clamp screws and sliding the blade).
    Loop a small rubber band from the bar's hook hole to the post.
17. **Servos.** Set each MG90S to its centre (1500 µs) using the console
    (`cal servo L ret 1500`, etc.) before fitting horns. Press a single-arm
    horn on pointing along +X (toward the column) and screw it. Fit an
    M2 × 8 screw through the horn's hole at r ≈ 8 mm from below so ~4 mm
    protrudes upward (this is the pin). Drop each servo into its bracket
    pocket (shaft up), secure with 2 × M2 tab screws.
18. **Servo brackets.** Slide the pin into the bar's underside slot through
    the plate's horn window while screwing the bracket to the plate's
    underside (4 × M3 × 8). Command `blades in` / `blades out`; adjust the
    endpoints with `cal servo` so that "in" gives 7 mm protrusion and "out"
    gives 1 mm inside the wall. Save.
19. **Beam S.** IR LED into one tube, phototransistor into the other
    (leads outward), hot-glue. **Beam W.** Phototransistor into the vertical
    hole above the slot from the top (leads up). The emitter goes into the
    sleeve (next step).
20. **Well sleeve.** Push the beam-W IR LED up the vertical hole in the
    sleeve's front wall until it seats under the 2 mm aperture; hot-glue.
    Stick 1.5 mm felt strips on both sides of the arm slot on the sleeve's
    and deck's inner back wall (recess provided). Screw the sleeve to the
    plate's underside (4 × M3 × 8), aligning the interior with the deck's.
21. **Column.** Push the two 8 mm rods up through the bottom plate holes
    into the top plate's blind holes; fix with grub screws top and bottom.
    Screw the microswitch to the inside of the back plate at the bottom
    (2 × M2), lever pointing up and toward the front.
22. **Carriage.** Press two LM8UU into the rear beam. Fit the T8 nut into
    the flange recess (flange up), 4 × M3 × 8. Screw the platform to the
    arm's spine from above (2 × M3 × 8, countersunk holes).
23. **Marry carriage and column.** Slide the carriage's bearings onto the
    rods from the top before the motor is fitted. Thread the lead screw
    down through the nut until it passes through the bottom clearance
    hole. Fit the coupler on the screw's top, then the NEMA 17 on the top
    plate (4 × M3 × 8) with its shaft in the coupler; tighten both coupler
    clamps.
24. **Column to deck.** From below the well deck, guide the carriage arm
    through the back wall's slot (deck + sleeve) while lowering the column
    flange onto the plate; 4 × M3 × 10 + nuts. Turn the coupler by hand:
    the platform must travel the full range without touching the walls.
25. **Bench test of the elevator and blades** (Stage 2): `home`, `z 0`,
    `z 20`, `cal home`, `blades in/out`. Then `cal knifetest` with a deck
    in the well (see §6.9).
26. **Join the modules.** Bolt the feeder deck's flange tabs to the well
    deck's (4 × M3 × 12 + nuts). The guide plate and the well slot bottom
    must be flush ±0.2 mm (shim with tape under a tab if not).
27. **Skirts.** Mount the rear skirt (4 × M3 × 10 into the bosses), then
    the front skirt; the column bottom must clear the rear skirt floor by
    ≥ 2 mm.

## 6.5 Stage C — electronics (steps 28–36)

28. **Perfboard.** Solder female headers for the ESP32, TMC2208 and DRV8833;
    the buck module on standoffs; the NPN with its 1 kΩ base resistor and
    three 150 Ω LED resistors; three 10 kΩ pull-downs; the 100 kΩ/33 kΩ
    divider with 100 nF; 100 µF across TMC2208 VM/GND and across DRV8833
    VM/GND; 470 µF on the 5 V rail; JST-XH headers J1–J16 (wiring diagram).
29. **Set the buck to 5.00 V** with nothing but the meter connected.
30. **Set TMC2208 Vref** to 0.9 V (≈ 0.65 A RMS) with the motor unplugged;
    tie MS1 and MS2 to 3V3 for 1/16 microstepping (or leave the module's
    default and set `STEPS_PER_MM` accordingly).
31. **Wire the harness**: stepper (4-pin JST), N20 motors (2-pin each),
    servos (3-pin each, 5 V + GND + signal), beams (4-pin each: LED+, LED−,
    PT collector 3V3, PT emitter → GPIO/10 kΩ), endstop (NC + COM), button,
    pixel (5 V via 1N4001, GND, data via 330 Ω), buzzer. Label every cable.
32. **Battery**: fuse holder in the positive lead, then the switch, then
    the perfboard's VBAT input; the charge jack directly across the pack's
    protected terminals (upstream of the switch). Velcro the pack to the
    front skirt's floor on a foam pad.
33. **Flash the firmware** (`pio run -t upload` or the Arduino IDE) with
    the battery disconnected; the ESP32 runs from USB.
34. **First power-up on battery**, USB connected, motors' JSTs unplugged:
    check `bat` reads within 0.2 V of the meter, `cal vbat <volts>`.
35. Plug in the sensors; `beams`; `cal beams`. Plug in the servos, N20s,
    stepper (power off when plugging the stepper).
36. Route cables away from the rollers and the elevator; zip-tie to the
    skirt walls; close the skirts (the decks are the lids).

## 6.6 Wiring diagram

`electronics/wiring-diagram.svg` — pinout table in `04-electronics.md` §4.3.

## 6.7 Calibration (first use)

Do these in order, with the serial console open.

| Step | Command | What it does / target |
|---|---|---|
| C1 | `cal vbat 12.30` (your meter reading) | battery gain |
| C2 | `cal beams` (machine empty) | thresholds = half of the clear signal; "WEAK" means realign the LED/PT |
| C3 | `home` | endstop found; platform at Z ≈ −26 |
| C4 | `cal home` (well empty) | platform finds beam S → Z origin defined |
| C5 | `blades in` / `blades out`, `cal servo …` | 7 mm in / 1 mm out, both sides equal ±0.3 |
| C6 | load a deck in the hopper; `probe`, `feed` ×20 | every feed "ok", B-block time steady ±10 %; adjust gate/PWM |
| C7 | put 30 cards in the well, `cal knifetest 15` | look through the finger notch: both blades in a card boundary, no card pushed in; if the blade lands consistently above the intended boundary use `cal knife -0.05`, below → `+0.05`; repeat with `cal knifetest 5` and `25` |
| C8 | `blades out`, `home`; remove the cards | |
| C9 | `test fixed 1`, deck in the hopper, press the button | machine prints PLAN; after the shuffle compare with `analyze_physical.py --compare` |

## 6.8 First-use checks

* Blades never move while the elevator moves (watch one full shuffle).
* Each card seats against the felt pad (look through the finger notch).
* No card is visible through the entry slot when the machine is idle.
* The stepper is cold to the touch after a shuffle; the servos are warm at
  most.
* Battery voltage after 5 shuffles has dropped by less than 0.15 V.
* `last` shows zero retries and zero double-feed suspects for a good deck.

## 6.9 Adjustments summary

| Symptom | Adjust |
|---|---|
| Two cards fed together | gate down 0.05 mm; less lid ballast; check the lip is smooth |
| Card not picked (FEED no card with a deck loaded) | gate up 0.05 mm; more ballast; clean O-rings with alcohol; raise `cal pwm feed` |
| Card stops before the pad (jam: well entry) | raise `cal pwm trans`; check the felt pad thickness; check the idler springs |
| Blade pushes a card instead of entering | `cal knife` by ±0.05; re-polish the bevel; check the well's stack is against the back wall (tilt, felt) |
| Cards hang on the blades after retract | more `GAP_CLOSE` (2.2 → 2.4) in `firmware/shuffler/config.h`; check bar travel returns fully |
| Stack measure fails | beam S LED/PT alignment, `cal beams` |

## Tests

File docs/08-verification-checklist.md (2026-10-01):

# 8. Verification checklist

★ = establishes randomness; the rest establishes reliability.

## A. Parts and mechanics

- [ ] `cad/check_clearance.sh` reports OK for all 17 checks after any CAD change.
- [ ] `cad/check_printability.py` reports ALL PARTS OK and `cad/check_clearance.sh` reports no COLLISION after any CAD change.
- [ ] All 24 STL files printed (30 pieces with duplicates, `cad/print-settings.md`); the feeder deck and the chute flat on glass (< 0.3 mm).
- [ ] The gate-window print ribs are cut off and filed flush; the gate block slides in freely.
- [ ] Every one of the 54 slots accepts a card by hand to the hub and releases it.
- [ ] Wheel spins freely on the rod, axial play < 0.5 mm, no wobble > 0.5 mm at the rim.
- [ ] With cards seated, no card touches the shroud in the upper half; in the lower half cards slide out ≤ 1.5 mm and ride the shroud without catching.
- [ ] Index tab passes the sensor with ≥ 1 mm clearance each side.
- [ ] Rollers turn freely; crowns 0.7 / 0.5 mm above their plates.
- [ ] Gate set by feeler gauge (0.40 passes, 0.55 blocked).
- [ ] The shutter blade slides 17.5° freely inside the shroud; closed it covers the window, open the window is clear; cards ride over its ramps without catching.
- [ ] At `entry k` the fin face is 0.4 mm below the plate plane at its tip (straight edge).
- [ ] With a card held halfway into the mouth, `jog 10` is refused (beam S interlock). Same for a card in the exit nip (beam X).
- [ ] Chute end wall felt fitted; finger opening usable.

## B. Electronics

- [ ] Buck 5.00 ± 0.05 V at 1 A; TMC Vref ≈ 1.4 V (≈ 1.0 A RMS); MS1/MS2 set; motor never hot-plugged.
- [ ] `bat` = multimeter ± 0.05 V after `cal vbat`.
- [ ] `beams`: B, E, S, X clear > 300 counts, blocked < 50 with a card; `index` shows TAB once per revolution.
- [ ] Fuse in the positive lead; charge jack upstream of the switch; charger LED indicates charging.

## C. Firmware

- [ ] `firmware/test_host` `make run` passes; `firmware/test_host/syntax_check.sh` passes.
- [ ] `test ref` on the ESP32 = `rng_reference.py --selftest` slot list. ★
- [ ] `test raw 65536` → `ent`: ≈ 8.0 bits/byte. ★
- [ ] `test seed 20`: 20 different keys. ★
- [ ] `test rng 100000` → `analyze_physical.py --slots`: all statistics within the uniform reference. ★
- [ ] Low-battery behaviour with a bench supply: warn 9.9 V, refuse 9.6 V, abort 9.3 V then unload-all recovers the cards.
- [ ] Error paths: index unplugged (E1), empty hopper (E2), cards left in the wheel (E4), a card placed by hand in an "empty" slot during loading (E11).

## D. Feeding (Stage 1)

- [ ] 100 consecutive single feeds, standard deck; B-block time spread < ±10 %.
- [ ] Same with a 0.25 mm deck and a 0.40 mm deck after re-setting the gate; with a worn deck.

## E. Wheel loading and unloading (Stages 2–3) ★

- [ ] `entry k` for k = 0, 13, 27, 40, 53 then a hand-fed card: beam E blocked and beam S clear every time (20 trials each).
- [ ] Mean index time ≤ 0.3 s (time 50 random `entry k` moves) with no skipped steps (`home` afterwards finds the index within ±0.2°).
- [ ] 20 fixed-seed shuffles: `last` shows ≤ 1 % corrections, direction-bias binomial p > 0.05, 0 lost cards, 0 double-feed suspects, ejected = loaded = 52 (`analyze_physical.py --log`).
- [ ] Predicted-vs-actual on the same 20 decks (`--compare`): identical.
- [ ] Repeat 5 decks each from a sorted, reversed and shuffled deck.
- [ ] Fault injection: `cal entry +1.5` → corrections show a directional excess; gate 0.8 mm → count warning. Restore.

## F. Whole machine

- [ ] 20 consecutive shuffles without error; time recorded (`cal show`).
- [ ] Card inspection after 50 shuffles under a lamp against 5 unused cards: no scratches, edge marks, corners.
- [ ] 200+ physical shuffles for `analyze_physical.py --decks`.
- [ ] Shuffles per charge measured and written into `04-electronics.md`.

## G. Documentation honesty

- [ ] Every measured number replaces its [EST] with [PHYS].
- [ ] Remaining [EST] items listed in `10-deliverables-and-gaps.md`.

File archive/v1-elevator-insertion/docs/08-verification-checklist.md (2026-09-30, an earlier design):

# 8. Verification checklist

Tick every item before trusting the machine for a game. Items marked ★ are
the ones that establish randomness; the others establish reliability.

## A. Printed parts and mechanics

- [ ] All 19 parts printed; no warping on the two decks (lay on glass: < 0.3 mm gap).
- [ ] Rollers turn freely; crowns 0.7 / 0.5 mm above the plate.
- [ ] Gate set with a feeler gauge; 0.40 mm passes, 0.55 mm does not (standard cards).
- [ ] Idler arm pivots freely, wheels touch the transport roller, springs compressed ~3 mm with the lid closed.
- [ ] Both blade bars slide 8 mm freely; blades 1 mm inside the wall when out, 7 mm in when in; blade edges polished, corners rounded.
- [ ] Platform travels −25 … +22 mm without touching the walls; no play in the T8 nut (< 0.05 mm).
- [ ] Endstop trips at Z ≈ −26 (`status` while jogging).
- [ ] Well and sleeve interiors aligned (run a card up and down the well by hand: no catch).
- [ ] Feeder plate and well slot bottom flush (±0.2 mm).
- [ ] Felt pads fitted; cards seat square against the back wall.

## B. Electronics

- [ ] Buck output 5.00 ± 0.05 V under a 1 A load.
- [ ] TMC2208 Vref 0.9 V; MS1/MS2 configured; motor wires never hot-plugged.
- [ ] `bat` matches the multimeter after `cal vbat` (± 0.05 V).
- [ ] `beams`: all three clear signals > 300 counts, blocked (card inserted by hand) < 50 counts.
- [ ] Endstop reads "hit" only when pressed (NC wiring verified by unplugging: must read hit → safe).
- [ ] Servos reach both endpoints without buzzing at the stops (endpoints are inside the mechanical range).
- [ ] Fuse in the positive lead; charge jack wired upstream of the switch; charger LED indicates charging.

## C. Firmware

- [ ] `firmware/test_host` `make run` passes (RNG core bit-exact with the Python reference).
- [ ] `test ref` on the ESP32 prints the same 52 gaps as `rng_reference.py --selftest`. ★
- [ ] `test raw 65536` → `ent` (or NIST STS) on the dump: ≈ 8.0 bits/byte, no test failing. ★
- [ ] `test seed 20`: 20 different keys (no repeats). ★
- [ ] `test rng 100000` → `analyze_physical.py --gaps`: all statistics within the uniform reference ranges. ★
- [ ] Low-battery behaviour tested with a bench supply: warn at 9.9 V, refuse at 9.6 V, abort-and-present at 9.3 V.
- [ ] Error paths tested: unplug the endstop (ERROR 1), empty hopper (ERROR 2), card left in the well (ERROR 4).

## D. Feeding reliability (Stage 1 of the prototype plan)

- [ ] 100 consecutive single feeds, standard deck: 0 double feeds, 0 misses, B-block time spread < ±10 %.
- [ ] Same with a thin deck (0.25 mm) and a thick custom deck (0.40 mm) after re-setting the gate.
- [ ] 100 feeds with a worn (used) deck.

## E. Insertion accuracy (Stage 2–3) ★

- [ ] `cal knifetest` at gaps 0, 5, 15, 25, 40 (deck of 52 in the well): blades enter a boundary cleanly every time, no card pushed.
- [ ] Predicted-vs-actual test, 20 fixed-seed shuffles (1040 insertions): ≤ 1 % off-by-one, direction-bias p > 0.05, 0 landed-on-top, 0 double feeds (`analyze_physical.py --compare`).
- [ ] Repeat the predicted-vs-actual test from a sorted deck, a reversed deck and a shuffled deck (5 each).
- [ ] Fault injection: gate at 0.8 mm → count warning appears; `cal knife +0.3` → bias test reports "+" direction, then restore.

## F. Whole-machine

- [ ] 20 consecutive shuffles without an error; time per shuffle recorded (`stats` via `cal show`).
- [ ] Card inspection after 50 shuffles: no scratches, no marked edges, no bent corners (compare with 5 unused cards from the same deck under a lamp).
- [ ] 200+ physical shuffles logged for `analyze_physical.py --decks` (sanity statistics).
- [ ] Battery: shuffles per charge measured and written into `04-electronics.md` in place of the estimate.

## G. Documentation honesty

- [ ] Every number in the docs that was measured on the build has replaced its [EST] with [PHYS] and the value.
- [ ] Items still marked [EST] are listed in `10-deliverables-and-gaps.md`.

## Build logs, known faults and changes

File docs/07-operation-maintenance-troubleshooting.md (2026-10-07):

# 7. Operation, maintenance, troubleshooting

## 7.1 Operating instructions

1. Switch on: green LED. Amber blinking = battery low (usable until refused).
2. Open the lid; put the deck in the hopper **face down**, short edge toward
   the wheel, resting against the gate; close the lid.
3. The chute must be empty (previous deck removed).
4. Press the button. Blue = loading (the wheel indexes for each card;
   about 26 s). Cyan = unloading (the wheel brings the first full slot to
   the exit, the shutter opens, then the wheel steps through the slots and
   cards slide into the chute; about 12 s).
5. Green + one beep: done. Lift the deck out of the chute.

Amber blinking + two beeps: the counts did not match (fewer cards loaded
than expected, fewer ejected than loaded, or a double-feed suspicion). The
deck is a valid ordering; re-run if it matters (re-running from any order
is uniform). Red blinking + three beeps: error; the serial console shows
the code. Press to clear. Hold 3 s: "unload all" — the shutter closes, the
wheel is homed and scanned, the first occupied slot is brought to the exit,
the shutter opens, and every occupied slot is emptied into the chute (also
the way to retrieve cards after a mid-shuffle stop).

`cal cards 54` for decks with jokers.

## 7.2 Jam recovery

* **Hopper / gate**: open the lid, lift the deck. The feed roller is under
  the floor slot.
* **Between gate and wheel**: lift the front of the entry idler arm
  against its springs and pull the card back, or push it fully into the
  slot. The wheel will not turn while a card bridges the mouth (beam S), so
  nothing moves while your fingers are there.
* **In the wheel**: hold the button 3 s (unload all). If a slot will not
  eject, run `shutter open` and pull the card out of the window by its
  edge; run `shutter close` before the wheel turns again. Or open the lid
  and reach in from the hopper side.
* **In the exit nip / chute**: lift the exit idler arm and pull the card
  through.

After any jam put all cards back in the hopper and start again.

## 7.3 Maintenance

| Interval | Task |
|---|---|
| Every 20 decks | Wipe the three rollers' O-rings and the four idler O-rings with isopropyl alcohol. |
| Every 50 decks | Blow dust out of the slot mouths (compressed air from the hopper side with the lid open, wheel turned by hand); blow off the three beams and the index sensor. |
| Every 200 decks or on double feeds | Re-set the gate with the feeler gauge; re-round the lip if grooved. |
| Yearly | Replace O-rings; check the shroud interior for polish marks (a strip of self-adhesive felt inside the shroud is an optional upgrade); check the wheel nuts are tight; re-run `cal beams`, `cal home`, `cal entry`, `cal exit`. |
| Battery | Store at 40–60 %; charge only with the 12.6 V adapter; replace when a charge no longer gives ~150 shuffles. |

Replaceable soft parts: roller and idler O-rings, felt strips, gate block.

## 7.4 Troubleshooting

| Symptom | Likely cause | Fix |
|---|---|---|
| ERROR 1 index not found | index LED or phototransistor wiring and alignment, tab broken | `beams` shows `index=TAB` when the tab is in the beam; turn the wheel by hand past 12 o'clock |
| ERROR 2 no deck | roller not touching, O-rings dirty, gate too low, beam B threshold | `probe` while watching `beams`; `cal beams`; gate +0.05 |
| ERROR 3 jam (feed) | wedge at the gate, idler too tight, or a card stuck in the slot mouth (beam S blocked; the wheel will not turn) | pull the card back or push it in; then see 6.9, `cal entry`, `cal pwm nipe` |
| ERROR 4 cards left in the wheel | previous run stopped | hold 3 s (unload all) |
| ERROR 5 RNG health | hardware RNG stuck | power-cycle; if persistent do not use for play |
| ERROR 6 battery | < 9.6 V | charge; hold 3 s to unload cards left in the wheel |
| ERROR 8 lost card | card left the feeder but is not in the slot or its neighbours | check the fin mouths; the card may be lying on the shroud: unload all |
| ERROR 9 eject problem | a card is stuck in the exit nip, or no card came out of a slot the map says is full | lift the exit idler; look in the exit window; `cal pwm nipx`, `cal exit` |
| ERROR 11 map | a slot that should be empty holds a card even after re-homing | hold 3 s to unload, then shuffle again; if it repeats, check the index and `cal entry` |
| Corrections logged in one direction (`last`) | entry plane trim | `cal entry ±0.1` |
| Cards rub the shroud loudly | shroud too close (print) | shim the shroud tabs with washers |
| Unload leaves a card in a slot | card seated too deep after sliding on the shroud, or exit trim | `cal exit`; check the slot mouth; the count warning tells you |
| Output deck not square | chute end wall felt missing, cards bouncing | felt; reduce `cal pwm nipx` |
| Shuffle > 60 s | retries (see `last`), slow wheel (`WHEEL_ACC_DPS2` still 900 from an old build), long timeouts | fix feeding first; acceleration 5000°/s² with Vref ≈ 1.4 V |
| Stepper stalls on long moves | Vref low, wheel rubbing the shroud, nut loose | Vref ≈ 1.4 V; lower `WHEEL_ACC_DPS2` to 3500 (≈ 0.3 s per index) |

## 7.5 Safety notes

* Lithium pack: protected pack + matching charger only; do not charge
  unattended on flammable surfaces; stop using a swollen or warm pack.
* Keep fingers out of the chute while unloading; the wheel and nips have
  little force but the stepper does not sense a finger.
* Idle draw ≈ 0.8 W: switch off after the game.

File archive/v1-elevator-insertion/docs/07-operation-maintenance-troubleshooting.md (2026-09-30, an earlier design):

# 7. Operation, maintenance, troubleshooting

## 7.1 Operating instructions

1. Switch on. The LED shows green (idle). Amber blinking = battery low
   (still usable until the machine refuses to start).
2. Open the lid, put the deck in the hopper **face down**, long edge along
   the machine, pushed gently toward the gate. Close the lid.
3. Make sure the well is empty (the previous deck removed).
4. Press the button once. Blue LED: shuffling. Expect 60–80 s for 52 cards
   (first builds).
5. Green LED and one beep: done. The elevator presents the deck 3 mm above
   the rim; pinch it through the finger notches and lift it out.
6. Press the button once more to lower the platform (or just load the next
   deck: the next shuffle homes first).

Amber blinking with two beeps after a shuffle: the card count differed from
the expected 52 (or a double feed was suspected). The deck is a valid but
possibly less random ordering; re-run the shuffle if it matters (a re-run
from any order is uniform).

Red blinking with three beeps: error. Serial console shows the code. Press
the button to clear; hold it 3 s to retract the blades, home and lower the
platform for jam access.

Setting 54 cards (jokers): serial `cal cards 54`.

## 7.2 Jam recovery

Cards are reachable without tools:

* **Hopper / gate**: open the lid, lift the deck out. The feed roller is
  visible through the floor slot.
* **Between gate and well** (the most likely place): lift the idler arm's
  front with a finger (it pivots) and pull the card back toward the hopper,
  or push it forward into the well with the gap still open (after an error
  the blades stay in and the gap stays open until you press the button).
* **In the well**: hold the button 3 s → blades out, platform down; lift the
  cards out through the top.

After any jam: put all cards back into the hopper and start again. The
algorithm is input-independent, so a restart from a half-shuffled deck is
just as random as from a fresh deck.

## 7.3 Maintenance

| Interval | Task |
|---|---|
| Every 20 decks | Wipe the roller O-rings and the idler O-rings with isopropyl alcohol on a lint-free cloth (card coating and dust reduce grip). |
| Every 50 decks | Blow dust off the three beam sensors (compressed air through the finger notch and the slot). Check the felt pads. |
| Every 200 decks or when double feeds start | Re-set the gate with the feeler gauge; check the gate lip for polish/grooves and re-round it. |
| Yearly | Replace the roller O-rings (nitrile hardens). Re-run `cal beams`, `cal home`, `cal knifetest`. Check the lead-screw nut for play (replace the brass nut). |
| Battery | Store at 40–60 % charge if unused for months; charge with the supplied 12.6 V adapter only; replace the pack when a full charge no longer gives ~100 shuffles. |

Replaceable soft parts: roller O-rings (M1), idler O-rings (M2), felt pads
(M4), gate block (printed), blades (brass, M3).

## 7.4 Troubleshooting

| Symptom | Likely cause | Fix |
|---|---|---|
| ERROR 1 (home) | endstop wiring (NC contact), lever bent, carriage stuck | `status` shows endstop state; check with the carriage pressed against the lever |
| ERROR 2 (no deck) with a deck loaded | feed roller not touching the card, O-rings dirty, gate too low, beam B threshold wrong | `probe` while watching `beams`; `cal beams`; gate +0.05 |
| ERROR 3 jam: pickup | as above, or a warped card | check the deck lies flat |
| ERROR 3 jam: gate/nip | card stuck at the gate (double feed wedge) or idler too tight | gate −0.05; check lip smoothness; weaker springs |
| ERROR 3 jam: well entry | gap not open (blade missed and the upper stack fell), card stopped short, W beam misaligned | `cal knifetest`; raise transport PWM; `beams` |
| ERROR 4 well not empty | cards left in the well, or beam S blocked by dirt | remove cards; clean |
| ERROR 5 RNG | hardware RNG health test failed (very unlikely) | power-cycle; if persistent the ESP32 board is faulty or `USE_BOOTLOADER_RANDOM` failed to link — do not use the machine for play until resolved |
| ERROR 6 battery | pack below 9.6 V | charge |
| ERROR 8 stack measure | beam S never blocked while raising | LED/PT alignment; threshold |
| Deck comes out with the input bottom card still at the bottom repeatedly | gap 0 never used: blade offset too high (systematic +1) | `cal knife -0.05`; run the predicted-vs-actual test |
| Cards stick together when lifted from the well | static (plastic cards) | rub the deck with a dryer sheet; fan the deck before loading |
| Shuffle takes > 100 s | many retries (see `last`), slow servo settle, low transport PWM | fix the feed first; reduce `SERVO_SETTLE_MS` to 150 if the servos are fast |
| Stepper skips (buzzing, then a wrong height) | Vref too low, coupler slipping, rods binding | Vref 0.9 V; tighten coupler; ream the column holes; grease the rods lightly |
| Blades do not fully retract | rubber band lost, bar binding in the loops | replace band; sand the bar |
| Power bank switches off (USB-C option) | idle current below the bank's threshold | set `KEEPALIVE_MS 10000` |

## 7.5 Safety notes

* Lithium pack: use only the protected pack and its matching charger; do
  not charge unattended on flammable surfaces; stop using a pack that
  swells or gets warm while idle.
* Keep fingers out of the well while the elevator moves; the blades and
  platform exert little force but the stepper does not know your finger is
  there.
* The stepper driver disables itself when idle; if the machine is left on,
  it draws about 0.75 W and the pack will empty in about a day.

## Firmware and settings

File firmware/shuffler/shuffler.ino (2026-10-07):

// shuffler.ino — main state machine for the WHEEL card shuffler (ESP32 DevKitC).
//
// One button: press = start / acknowledge; hold 3 s = unload all (home, scan, empty every occupied slot).
// Serial console at 115200: type `help`.
//
// Shuffle = LOAD phase (each card from the hopper into a uniformly random empty slot of the 54-slot
// wheel) + UNLOAD phase (slots emptied in slot order into the chute).  See docs/02-mathematics.md.
#include <Arduino.h>
#include "config.h"
#include "platform.h"
#include "hardware.h"
#include "motion.h"
#include "rng.h"
#include "sha256.h"
#include "shuffle_core.h"
#include "storage.h"

Calibration cal;

enum State { ST_IDLE, ST_LOADING, ST_UNLOADING, ST_DONE, ST_ERROR };
static State state = ST_IDLE;
static int error_code = 0;
enum { E_NONE = 0, E_HOME = 1, E_NO_DECK = 2, E_JAM_FEED = 3, E_WHEEL_NOT_EMPTY = 4, E_RNG = 5, E_LOWBAT = 6, E_TOO_MANY = 7, E_LOST_CARD = 8, E_JAM_EJECT = 9, E_COUNT = 10, E_MAP = 11 };

struct ShuffleLog {
    uint8_t  n;                        // cards loaded
    uint8_t  slot_of_card[MAX_CARDS];  // realised slot (after any correction)
    uint8_t  intended[MAX_CARDS];      // slot drawn by the RNG
    uint8_t  order[MAX_CARDS];         // predicted output order (bottom..top, input index)
    uint8_t  retries[MAX_CARDS];
    uint8_t  corrections, double_suspects, eject_double_suspects, ejected;
    uint32_t ms_load, ms_unload;
    uint8_t  key[32]; uint64_t counter; bool fixed_seed;
} last;

void cli_init(); void cli_poll(); bool cli_fixed_seed_pending(uint32_t* seed);

static void set_error(int code, const char* text) {
    error_code = code; state = ST_ERROR;
    feeder_stop(); eject_stop(); motors_sleep(true); wheel_idle();
    ui_blink(C_ERROR, 500); ui_beep(3, 120, 1800);
    if (code == E_JAM_FEED || code == E_JAM_EJECT) cal.total_jams++;
    cal_save(cal);
    Serial.printf("ERROR %d: %s\n", code, text);
}

// ---------------------------------------------------------------- seeding
static bool seed_drbg(Drbg* d, bool fixed, uint32_t fixed_seed) {
    cal.shuffle_counter++;
    if (fixed) { char buf[40]; int n = snprintf(buf, sizeof buf, "fixed-seed:%lu", (unsigned long)fixed_seed);
        uint8_t key[32]; sha256((const uint8_t*)buf, n, key); drbg_seed_key(d, key, cal.shuffle_counter);
        memcpy(last.key, key, 32); last.fixed_seed = true; last.counter = cal.shuffle_counter; return true; }
    uint8_t hw[64], jit[32];
    jitter_add(micros()); jitter_add((uint32_t)(battery_volts() * 100000.0f)); jitter_add(esp_random());
    hw_random_bytes(hw, sizeof hw); jitter_snapshot(jit);
    bool ok = drbg_seed(d, hw, jit, cal.boot_counter, cal.shuffle_counter);
    memcpy(last.key, d->key, 32); last.fixed_seed = false; last.counter = cal.shuffle_counter;
    return ok;
}

// ---------------------------------------------------------------- one shuffle
static bool feed_with_retries(uint8_t i, FeedResult* out) {
    FeedStats st; FeedResult r = FEED_OK;
    for (int attempt = 0; attempt <= FEED_RETRIES; attempt++) {
        last.retries[i] = attempt;
        r = feeder_feed_one(&st);
        if (r == FEED_OK) { if (st.double_suspect) last.double_suspects++; *out = r; return true; }
        if (r == FEED_NO_CARD || r == FEED_NOT_SEATED) { *out = r; return false; }   // hopper empty / card in a neighbour slot
        // jam or card stuck in the mouth: pull it back with a reverse pulse and try the same slot again.
        // (Retrying into the same, still empty slot does not change the output distribution.)
        Serial.printf("# card %u: %s, retry %d\n", i, feed_result_name(r), attempt + 1);
        feeder_reverse_pulse();
    }
    *out = r; return false;
}

// After a feed, the card should be in slot s (beam E blocked at the entry).  If not, look one slot each
// side; return the slot where it was found or -1.
static int locate_card(uint8_t s, bool occupied[N_SLOTS_HW]) {
    if (beam_blocked_now(BEAM_E)) return s;
    int cands[2] = { (s + 1) % N_SLOTS_HW, (s + N_SLOTS_HW - 1) % N_SLOTS_HW };
    for (int c = 0; c < 2; c++) {
        if (occupied[cands[c]]) continue;                    // was already occupied: a card there is not the new one
        if (!wheel_fin_to_entry((uint8_t)cands[c])) return -1;
        delay(30);
        if (beam_blocked_now(BEAM_E)) return cands[c];
    }
    return -1;
}

// Open only with the first occupied slot at the exit: opened elsewhere, cards over the window slide out and the next move drags them.
static bool unload_open(const bool occupied[N_SLOTS_HW]) {
    for (uint8_t s = 0; s < N_SLOTS_HW; s++)
        if (occupied[s]) { if (!wheel_fin_to_exit(s)) return false; break; }
    shutter_set(SHUTTER_OPEN);
    return true;
}

static void run_shuffle(bool fixed, uint32_t fixed_seed) {
    uint32_t t0 = millis();
    state = ST_LOADING; ui_color(C_BUSY);
    memset(&last, 0, sizeof last);
    if (battery_volts() < VBAT_REFUSE) { set_error(E_LOWBAT, "battery too low to start"); return; }

    Drbg d;
    if (!seed_drbg(&d, fixed, fixed_seed)) { set_error(E_RNG, "hardware RNG health test failed"); return; }
    if (fixed) {   // predicted-vs-actual test: print the plan before moving
        uint8_t sl[MAX_CARDS], o[MAX_CARDS]; Drbg dd = d; uint8_t n = cal.expected_cards;
        slots_assign(&dd, n, N_SLOTS_HW, sl); predict_order_from_slots(n, sl, o);
        Serial.printf("PLAN cards=%u seed=%lu\nPLAN slots:", n, (unsigned long)fixed_seed);
        for (int i = 0; i < n; i++) Serial.printf(" %u", sl[i]);
        Serial.print("\nPLAN order(bottom..top, input index):"); for (int i = 0; i < n; i++) Serial.printf(" %u", o[i]); Serial.println();
    }

    shutter_power(true); shutter_set(SHUTTER_CLOSED);
    if (!wheel_path_clear()) { set_error(E_JAM_FEED, "a card bridges the wheel and the feeder or chute: remove it"); return; }
    if (!wheel_home()) { set_error(E_HOME, "wheel index not found"); return; }
    bool occupied[N_SLOTS_HW] = {false};
#if SCAN_AT_START
    int found_cards = wheel_scan(occupied);
    if (found_cards < 0) { set_error(E_JAM_FEED, "a card bridges the wheel and the feeder or chute"); return; }
    if (found_cards != 0) { set_error(E_WHEEL_NOT_EMPTY, "cards left in the wheel: hold the button to unload"); return; }
#endif
    if (!feeder_probe_hopper()) { set_error(E_NO_DECK, "no deck in the hopper"); return; }

    // ---- LOAD: card i -> uniform among the slots the firmware knows to be empty (exact Fisher–Yates)
    uint8_t empty[N_SLOTS_HW]; uint8_t n_empty = N_SLOTS_HW; for (uint8_t s = 0; s < N_SLOTS_HW; s++) empty[s] = s;
    uint8_t n = 0; bool lowbat = false;
    for (uint8_t i = 0; i < N_SLOTS_HW; i++) {
        uint8_t idx = (uint8_t)drbg_uniform(&d, n_empty);
        uint8_t s = empty[idx];
        last.intended[i] = s;
        if (!wheel_fin_to_entry(s)) { set_error(E_JAM_FEED, "a card bridges the wheel and a fixed part"); return; }
        // The target must be empty. If not, the map is wrong (lost steps or an unnoticed misplaced card):
        // re-home once (fixes lost steps); if it is still occupied, stop rather than guess.
        if (beam_blocked_now(BEAM_E)) {
            Serial.printf("# slot %u should be empty but beam E is blocked: re-homing\n", s);
            if (!wheel_home() || !wheel_fin_to_entry(s)) { set_error(E_HOME, "re-homing failed"); return; }
            if (beam_blocked_now(BEAM_E)) { set_error(E_MAP, "unexpected card in a slot the map says is empty"); return; }
        }
        FeedResult r;
        if (!feed_with_retries(i, &r)) {
            if (r == FEED_NO_CARD) break;                                      // hopper empty
            if (r == FEED_NOT_SEATED) {
#if VERIFY_AFTER_INSERT
                int found = locate_card(s, occupied);
                if (found < 0) { set_error(E_LOST_CARD, "card left the feeder but is not in the slot or its neighbours"); return; }
                if (found != s) { last.corrections++; cal.total_corrections++; Serial.printf("# card %u landed in slot %d (intended %u): map corrected\n", i, found, s); }
                s = (uint8_t)found;
#else
                set_error(E_LOST_CARD, "card not seen in the slot"); return;
#endif
            } else { set_error(E_JAM_FEED, feed_result_name(r)); return; }   // wheel stays put; the interlock blocks moves while beam S is blocked
        }
        // remove the realised slot from the empty list (swap-remove; order irrelevant for uniformity)
        occupied[s] = true; last.slot_of_card[i] = s; n = i + 1;
        uint8_t k = 0; while (k < n_empty && empty[k] != s) k++;
        if (k < n_empty) { empty[k] = empty[n_empty - 1]; n_empty--; }
        if (n_empty == 0) break;
        if (battery_volts() < VBAT_ABORT) { lowbat = true; break; }
        ui_tick();
    }
    feeder_stop();
    last.n = n; last.ms_load = millis() - t0;
    if (n == 0) { set_error(E_NO_DECK, "no card could be fed"); return; }

    // ---- UNLOAD: slots in increasing order into the chute
    state = ST_UNLOADING; ui_color(C_UNLOAD);
    uint32_t t1 = millis();
    if (!unload_open(occupied)) { set_error(E_JAM_EJECT, "a card is still in the exit nip"); return; }
    uint8_t ejected = 0;
    for (uint8_t s = 0; s < N_SLOTS_HW; s++) {
        if (!occupied[s]) continue;
        if (!wheel_fin_to_exit(s)) { set_error(E_JAM_EJECT, "a card is still in the exit nip"); return; }
        EjectResult er = EJECT_OK; EjectStats es;
        for (int attempt = 0; attempt < 3; attempt++) {
            er = eject_one(&es);
            if (er == EJECT_OK) break;
            Serial.printf("# slot %u: eject %s, retry %d\n", s, er == EJECT_NO_CARD ? "no card" : "jam", attempt + 1);
            if (er == EJECT_JAM) { motor_run(M_NIPX, -cal.nipx_pwm); delay(T_REVERSE_MS); eject_stop(); delay(60); }
        }
        if (er == EJECT_JAM) { set_error(E_JAM_EJECT, "card stuck in the exit nip"); return; }
        // No card reached beam X. It may be hanging half out of the window, where turning the wheel would
        // tear it, so stop and let the user look rather than rotate on.
        if (er == EJECT_NO_CARD) { set_error(E_JAM_EJECT, "a card did not come out at the exit: check the exit window"); return; }
        ejected++; if (es.double_suspect) last.eject_double_suspects++;
        ui_tick();
    }
    shutter_set(SHUTTER_CLOSED); shutter_power(false); motors_sleep(true); wheel_idle();
    last.ms_unload = millis() - t1; last.ejected = ejected;
    predict_order_from_slots(n, last.slot_of_card, last.order);
    cal.total_cards += n; cal.last_shuffle_ms = millis() - t0; cal_save(cal);

    unsigned retries = 0; for (int i = 0; i < n; i++) retries += last.retries[i];
    Serial.printf("DONE loaded=%u ejected=%u load=%lu ms unload=%lu ms retries=%u corrections=%u double_suspects in/out=%u/%u\n",
                  n, ejected, (unsigned long)last.ms_load, (unsigned long)last.ms_unload, retries, last.corrections, last.double_suspects, last.eject_double_suspects);
    if (lowbat) { set_error(E_LOWBAT, "battery low: stopped early; loaded cards are in the chute, the rest are still in the hopper"); return; }
    state = ST_DONE;
    if (ejected != n || n != cal.expected_cards || last.double_suspects || last.eject_double_suspects) {
        ui_blink(C_WARN, 400); ui_beep(2, 200, 1500);
        Serial.printf("WARN expected %u, loaded %u, ejected %u (double-card suspects in/out %u/%u): consider re-running\n",
                      cal.expected_cards, n, ejected, last.double_suspects, last.eject_double_suspects);
    } else { ui_color(C_DONE); ui_beep(1, 250, 2600); }
}

void shuffle_print_last() {
    if (last.n == 0) { Serial.println("no shuffle yet"); return; }
    Serial.printf("LAST loaded=%u ejected=%u load=%lu ms unload=%lu ms seed=%s counter=%llu key=", last.n, last.ejected, (unsigned long)last.ms_load,
                  (unsigned long)last.ms_unload, last.fixed_seed ? "fixed" : "hardware", (unsigned long long)last.counter);
    for (int i = 0; i < 32; i++) Serial.printf("%02x", last.key[i]);
    Serial.print("\nLAST intended slots:"); for (int i = 0; i < last.n; i++) Serial.printf(" %u", last.intended[i]);
    Serial.print("\nLAST realised slots:"); for (int i = 0; i < last.n; i++) Serial.printf(" %u", last.slot_of_card[i]);
    Serial.print("\nLAST order(bottom..top, input index):"); for (int i = 0; i < last.n; i++) Serial.printf(" %u", last.order[i]);
    Serial.print("\nLAST retries:"); for (int i = 0; i < last.n; i++) Serial.printf(" %u", last.retries[i]);
    Serial.println();
}

// ---------------------------------------------------------------- recovery: unload whatever is in the wheel
static void unload_all() {
    ui_color(C_CAL); feeder_stop();
    shutter_power(true); shutter_set(SHUTTER_CLOSED);   // may still be open after ERROR 9 or `shutter open`
    if (!wheel_path_clear()) { set_error(E_JAM_FEED, "a card bridges the wheel and a fixed part: remove it by hand first"); return; }
    if (!wheel_home()) { set_error(E_HOME, "wheel index not found"); return; }
    bool occ[N_SLOTS_HW]; int n = wheel_scan(occ);
    if (n < 0) { set_error(E_JAM_FEED, "a card bridges the wheel and a fixed part: remove it by hand"); return; }
    if (!unload_open(occ)) { set_error(E_JAM_EJECT, "unload stopped: check the exit window and nip"); return; }
    for (uint8_t s = 0; s < N_SLOTS_HW; s++) if (occ[s]) {
        EjectStats es;
        if (!wheel_fin_to_exit(s) || eject_one(&es) != EJECT_OK) { set_error(E_JAM_EJECT, "unload stopped: check the exit window and nip"); return; }
    }
    shutter_set(SHUTTER_CLOSED); shutter_power(false); motors_sleep(true); wheel_idle();
    Serial.printf("# unloaded %d cards\n", n);
    state = ST_IDLE; ui_color(C_IDLE);
}

// ---------------------------------------------------------------- button
static void handle_button() {
    static uint32_t down_since = 0; static bool was_down = false;
    bool d = button_down();
    if (d && !was_down) { down_since = millis(); jitter_add(micros()); }
    if (!d && was_down) {
        uint32_t held = millis() - down_since;
        if (held > 30 && held < BUTTON_LONG_MS) {
            if (state == ST_DONE || state == ST_ERROR) { state = ST_IDLE; ui_color(C_IDLE); }
            else if (state == ST_IDLE) { uint32_t s; bool fixed = cli_fixed_seed_pending(&s); run_shuffle(fixed, s); }
        } else if (held >= BUTTON_LONG_MS) unload_all();
    }
    was_down = d;
}

// ---------------------------------------------------------------- Arduino
void setup() {
    Serial.begin(115200); delay(200);
    cal_load(cal); cal.boot_counter++; cal_save(cal);
    stepper_init(); shutter_init(); motors_init(); sensors_init(); ui_init(); cli_init();
    ui_color(C_IDLE);
    Serial.println("\n# wheel card shuffler firmware — type `help` for the serial console");
    cal_print(cal);
    jitter_add(esp_random()); jitter_add(micros());
    float v = battery_volts(); Serial.printf("# battery %.2f V\n", v);
    if (v < VBAT_WARN) ui_blink(C_LOWBAT, 1000);
}
void loop() {
    cli_poll(); handle_button(); ui_tick();
    static uint32_t last_bat = 0;
    if (millis() - last_bat > 5000) { last_bat = millis(); if (state == ST_IDLE) { float v = battery_volts(); if (v < VBAT_WARN) ui_blink(C_LOWBAT, 1000); else ui_color(C_IDLE); } }
#if KEEPALIVE_MS > 0
    static uint32_t last_ka = 0; if (millis() - last_ka > KEEPALIVE_MS) { last_ka = millis(); stepper_enable(true); delay(150); stepper_enable(false); }
#endif
    delay(5);
}

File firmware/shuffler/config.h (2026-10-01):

// config.h — pins, mechanical constants, defaults for the WHEEL shuffler.  Edit here, not in the modules.
#pragma once
#include <stdint.h>

// ---------------- pins (ESP32 DevKitC, see docs/04-electronics.md §4.3) ----------------
#define PIN_STEP       25
#define PIN_DIR        26
#define PIN_STEP_EN    27      // TMC2208 EN, active low
#define PIN_FEED_IN1   16      // DRV8833 #1 AIN1 (PWM)   feed roller
#define PIN_FEED_IN2   17      // DRV8833 #1 AIN2
#define PIN_NIPE_IN1   4       // DRV8833 #1 BIN1 (PWM)   entry nip roller
#define PIN_NIPE_IN2   5       // DRV8833 #1 BIN2
#define PIN_NIPX_IN1   15      // DRV8833 #2 AIN1 (PWM)   exit nip roller
#define PIN_NIPX_IN2   2       // DRV8833 #2 AIN2
#define PIN_DRV_SLEEP  23      // both DRV8833 nSLEEP
#define PIN_SERVO      18      // shutter servo
#define PIN_IR_EN      13      // NPN base: switches the three IR emitters
#define PIN_PIXEL      14      // WS2812B
#define PIN_BUZZER     33
#define PIN_BEAM_B     34      // ADC1  gate beam (feeder)
#define PIN_BEAM_E     35      // ADC1  entry beam: card present in the slot at the entry (oblique, tower to tower)
#define PIN_BEAM_S     32      // ADC1  seat beam: blocked while a card still bridges the plate and the slot mouth
#define PIN_BEAM_X     36      // ADC1  exit beam (card leaving through the chute)
#define PIN_VBAT       39      // ADC1  battery divider
#define PIN_INDEX      19      // index phototransistor, digital, 10 k pull-down (LOW when the disc tab blocks the beam)
#define PIN_BUTTON     21      // momentary to GND
#define PIN_DECK       22      // optional TCRT5000 DO (unused by default)

// ---------------- wheel geometry (see cad/params.scad) ----------------
#define N_SLOTS_HW        54
#define PITCH_DEG         (360.0f / N_SLOTS_HW)   // 6.6667
#define ENTRY_FIN_DEG     46.667f   // fin k's CCW face here → card enters slot k
#define EXIT_FIN_DEG      208.333f  // fin k+1's CW face here → card leaves slot k
#define INDEX_TAB_DEG     90.0f     // angle of the disc tab when the wheel reference (fin 0) is at 0°
#define STEPS_PER_REV     3200.0f   // 200 full steps × 1/16 microstepping, direct drive
#define WHEEL_VMAX_DPS    360.0f    // deg/s. Keep ≤ 360: faster spins fling cards outward in the open upper half
#define WHEEL_VMIN_DPS    20.0f
#define WHEEL_ACC_DPS2    5000.0f   // deg/s². Mean index (90°) ≈ 0.25 s; needs ≈ 10 N·cm, so set TMC Vref ≈ 1.4 V (≈ 1.0 A RMS)
#define WHEEL_V_HOME_DPS  90.0f
#define WHEEL_V_SCAN_DPS  120.0f
#define STEP_PULSE_US     3

// ---------------- shutter servo ----------------
#define SERVO_FREQ_HZ     50
#define SERVO_US_MIN      500
#define SERVO_US_MAX      2500
#define SHUTTER_CLOSED_US_DEFAULT 1150
#define SHUTTER_OPEN_US_DEFAULT   1850
#define SHUTTER_SETTLE_MS 250

// ---------------- feeder / nips ----------------
#define FEED_PWM_DEFAULT   160     // 0..255 on the 5 V rail
#define NIPE_PWM_DEFAULT   210
#define NIPX_PWM_DEFAULT   230
#define MOTOR_PWM_HZ       20000
#define T_PICK_MS          800     // beam B must block (card picked) within this
#define T_E_BLOCK_MS       900     // beam E must block (card reached the slot mouth)
#define T_B_CLEAR_MS       900     // beam B must clear (trailing edge past the gate)
#define T_SEAT_MS          250     // extra nip run after B clears (card slides to the hub)
#define T_SEAT_WAIT_MS     400     // after the nip stops: time allowed for beam S to clear (card slid in)
#define T_NUDGE_MS         150     // entry-nip pulse to push a card that stopped in the slot mouth
#define T_X_BLOCK_MS       700     // unload: beam X must block after the nip starts
#define T_X_CLEAR_MS       700     // unload: beam X must clear (card fully out)
#define T_REVERSE_MS       150
#define FEED_RETRIES       2
#define PROBE_MS           600
#define DOUBLE_FEED_RATIO  1.30f   // beam B (entry) or beam X (exit) block time vs running median → double-card suspect

// ---------------- sensors ----------------
#define BEAM_THRESH_DEFAULT 400
#define BEAM_SETTLE_US      250
#define BEAM_SAMPLES        2
#define VBAT_DIVIDER        4.03f
#define VBAT_WARN           9.9f
#define VBAT_REFUSE         9.6f
#define VBAT_ABORT          9.3f

// ---------------- behaviour ----------------
#define EXPECTED_CARDS_DEFAULT 52
#define BUTTON_LONG_MS     3000
#define IDLE_DISABLE_MS    2000
#define KEEPALIVE_MS       0
#define USE_BOOTLOADER_RANDOM 1
#define SCAN_AT_START      1       // rotate once and verify the wheel is empty before loading
#define VERIFY_AFTER_INSERT 1      // read beam E after each insertion; search ±1 slot if not found
#define ENTRY_TRIM_DEFAULT -0.3f  // deg: fin sits 0.4 mm below the card plane at its tip, so the card rides onto the lead-in
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

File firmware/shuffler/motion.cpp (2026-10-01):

// motion.cpp
#include "motion.h"
#include "hardware.h"
#include <math.h>

static const float SPD = STEPS_PER_REV / 360.0f;   // steps per degree
static float s_angle = 0;                          // deg, CCW positive, fin-0 reference

static float wrap360(float a) { while (a < 0) a += 360; while (a >= 360) a -= 360; return a; }
float wheel_angle() { return s_angle; }
void  wheel_idle() { stepper_enable(false); }
static bool stop_on_index() { return index_active(); }

bool wheel_path_clear() {
    beams_poll();
    if (beam_blocked(BEAM_S)) { Serial.println("# wheel move refused: a card bridges the entry (beam S)"); return false; }
    if (beam_blocked(BEAM_X)) { Serial.println("# wheel move refused: a card is in the exit nip (beam X)"); return false; }
    return true;
}

bool wheel_home() {
    if (!wheel_path_clear()) return false;
    // leave the tab if we are on it, then rotate CCW until the tab blocks the index beam; approach slowly for repeatability
    if (index_active()) stepper_move((long)(15 * SPD), WHEEL_V_HOME_DPS, WHEEL_ACC_DPS2);
    stepper_move((long)(370 * SPD), WHEEL_V_HOME_DPS, WHEEL_ACC_DPS2, stop_on_index);
    if (!index_active()) return false;
    stepper_move(-(long)(4 * SPD), WHEEL_V_HOME_DPS, WHEEL_ACC_DPS2);
    stepper_move((long)(8 * SPD), 15.0f, WHEEL_ACC_DPS2, stop_on_index);
    if (!index_active()) return false;
    stepper_set_pos(0);
    s_angle = wrap360(cal.home_offset_deg);
    return true;
}

bool wheel_goto(float target, float vmax) {
    target = wrap360(target);
    float d = target - s_angle;
    if (d > 180) { d -= 360; }
    if (d < -180) { d += 360; }          // shortest path
    long steps = lroundf(d * SPD);
    if (steps == 0) return true;
    if (!wheel_path_clear()) return false;
    stepper_move(steps, vmax, WHEEL_ACC_DPS2);
    s_angle = wrap360(s_angle + steps / SPD);
    return true;
}
bool wheel_fin_to_entry(uint8_t fin) { return wheel_goto(ENTRY_FIN_DEG + cal.entry_trim_deg - fin * PITCH_DEG); }
bool wheel_fin_to_exit(uint8_t slot) { return wheel_goto(EXIT_FIN_DEG + cal.exit_trim_deg - (slot + 1) * PITCH_DEG); }

int wheel_scan(bool occupied[N_SLOTS_HW]) {
    int n = 0;
    for (int s = 0; s < N_SLOTS_HW; s++) {
        if (!wheel_fin_to_entry((uint8_t)s)) return -1;
        delay(30);
        occupied[s] = beam_blocked_now(BEAM_E);
        n += occupied[s];
    }
    return n;
}

// ============================================================ feeder
static uint32_t s_median_b = 0, s_median_x = 0;
// Running-median-ish double-card heuristic shared by the entry (beam B) and exit (beam X).
static bool double_check(uint32_t* median, uint32_t ms) {
    if (*median == 0) { *median = ms; return false; }
    bool suspect = ms > (uint32_t)(*median * DOUBLE_FEED_RATIO);
    if (!suspect) *median = (*median * 7 + ms) / 8;    // suspects do not drag the median up
    return suspect;
}
const char* feed_result_name(FeedResult r) {
    switch (r) { case FEED_OK: return "ok"; case FEED_NO_CARD: return "no card"; case FEED_JAM_PICK: return "jam: pickup";
        case FEED_JAM_ENTRY: return "jam: gate to wheel"; case FEED_JAM_CLEAR: return "jam: not clearing gate";
        case FEED_NOT_SEATED: return "card not in the target slot"; case FEED_STUCK_MOUTH: return "card stuck in the slot mouth"; }
    return "?";
}
void feeder_stop() { motor_run(M_FEED, 0); motor_run(M_NIPE, 0); }
static bool wait_beam(Beam b, bool want_blocked, uint32_t timeout_ms) {
    uint32_t t0 = millis(); while (millis() - t0 < timeout_ms) { beams_poll(); if (beam_blocked(b) == want_blocked) return true; } return false;
}
bool feeder_probe_hopper() {
    motors_sleep(false); beams_poll();
    if (beam_blocked(BEAM_B)) return true;
    motor_run(M_FEED, cal.feed_pwm); bool got = wait_beam(BEAM_B, true, PROBE_MS); motor_run(M_FEED, 0);
    return got;
}
FeedResult feeder_feed_one(FeedStats* st) {
    st->b_block_ms = 0; st->double_suspect = false;
    motors_sleep(false);
    motor_run(M_NIPE, cal.nipe_pwm); motor_run(M_FEED, cal.feed_pwm);
    if (!wait_beam(BEAM_B, true, T_PICK_MS)) { feeder_stop(); return FEED_NO_CARD; }
    uint32_t t_block = millis();
    if (!wait_beam(BEAM_E, true, T_E_BLOCK_MS)) { feeder_stop(); return beam_blocked_now(BEAM_S) ? FEED_STUCK_MOUTH : FEED_JAM_ENTRY; }   // leading edge inside the slot
    if (!wait_beam(BEAM_B, false, T_B_CLEAR_MS)) { feeder_stop(); return FEED_JAM_CLEAR; }      // trailing edge past the gate
    motor_run(M_FEED, 0);
    st->b_block_ms = millis() - t_block;
    delay(T_SEAT_MS);                                                                          // nip pushes the rest; card slides to the hub
    motor_run(M_NIPE, 0);
    st->double_suspect = double_check(&s_median_b, st->b_block_ms);
    // the trailing edge must leave the mouth (beam S clear); nudge with the nip if it stopped there
    bool seated = wait_beam(BEAM_S, false, T_SEAT_WAIT_MS);
    for (int k = 0; !seated && k < 2; k++) {
        motor_run(M_NIPE, cal.nipe_pwm); delay(T_NUDGE_MS); motor_run(M_NIPE, 0);
        seated = wait_beam(BEAM_S, false, T_SEAT_WAIT_MS);
    }
    if (!seated) return FEED_STUCK_MOUTH;
    delay(40);
    if (!beam_blocked_now(BEAM_E)) return FEED_NOT_SEATED;                                     // card should now sit in the slot at the entry
    return FEED_OK;
}
void feeder_reverse_pulse() { motors_sleep(false); motor_run(M_FEED, -cal.feed_pwm); motor_run(M_NIPE, -cal.nipe_pwm); delay(T_REVERSE_MS); feeder_stop(); delay(60); }

// ============================================================ unload
void eject_stop() { motor_run(M_NIPX, 0); }
EjectResult eject_one(EjectStats* st) {
    st->x_block_ms = 0; st->double_suspect = false;
    motors_sleep(false);
    motor_run(M_NIPX, cal.nipx_pwm);
    if (!wait_beam(BEAM_X, true, T_X_BLOCK_MS)) { eject_stop(); return EJECT_NO_CARD; }
    uint32_t t0 = millis();
    if (!wait_beam(BEAM_X, false, T_X_CLEAR_MS)) { eject_stop(); return EJECT_JAM; }
    st->x_block_ms = millis() - t0;
    // Two cards that left one slot together are usually offset by a few mm and block beam X for longer.
    // Two perfectly stacked cards are NOT detectable this way; the end-of-shuffle count catches those.
    st->double_suspect = double_check(&s_median_x, st->x_block_ms);
    delay(60); eject_stop();
    return EJECT_OK;
}

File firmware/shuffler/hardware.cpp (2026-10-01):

// hardware.cpp — see hardware.h
#include "hardware.h"
#include "platform.h"
#include "rng.h"
#include <math.h>

// ============================================================ stepper
static long s_pos = 0; static bool s_enabled = false;
void stepper_init() { pinMode(PIN_STEP, OUTPUT); pinMode(PIN_DIR, OUTPUT); pinMode(PIN_STEP_EN, OUTPUT);
    digitalWrite(PIN_STEP, LOW); digitalWrite(PIN_DIR, LOW); digitalWrite(PIN_STEP_EN, HIGH); }
void stepper_enable(bool on) { digitalWrite(PIN_STEP_EN, on ? LOW : HIGH); if (on && !s_enabled) delay(5); s_enabled = on; }
long stepper_pos() { return s_pos; }
void stepper_set_pos(long steps) { s_pos = steps; }

long stepper_move(long steps, float vmax_dps, float acc_dps2, bool (*stop_if)()) {
    if (steps == 0) return 0;
    stepper_enable(true);
    bool fwd = steps > 0;
    digitalWrite(PIN_DIR, fwd ? HIGH : LOW); delayMicroseconds(10);
    const float spd = STEPS_PER_REV / 360.0f;        // steps per degree
    long n = labs(steps), made = 0;
    for (long i = 0; i < n; i++) {
        if (stop_if && stop_if()) break;
        float s_deg = (float)i / spd, r_deg = (float)(n - i) / spd;
        float v = vmax_dps;
        float va = sqrtf(2.0f * acc_dps2 * s_deg + WHEEL_VMIN_DPS * WHEEL_VMIN_DPS);
        float vd = sqrtf(2.0f * acc_dps2 * r_deg + WHEEL_VMIN_DPS * WHEEL_VMIN_DPS);
        if (va < v) { v = va; }
        if (vd < v) { v = vd; }
        if (v < WHEEL_VMIN_DPS) { v = WHEEL_VMIN_DPS; }
        uint32_t period_us = (uint32_t)(1e6f / (v * spd));
        digitalWrite(PIN_STEP, HIGH); delayMicroseconds(STEP_PULSE_US); digitalWrite(PIN_STEP, LOW);
        if (period_us > STEP_PULSE_US) delayMicroseconds(period_us - STEP_PULSE_US);
        s_pos += fwd ? 1 : -1; made++;
    }
    return fwd ? made : -made;
}

// ============================================================ shutter servo
static ShutterState s_shutter = SHUTTER_CLOSED;
static uint32_t us_to_duty(uint16_t us) { return (uint32_t)((uint64_t)us * 65535ULL / 20000ULL); }
void shutter_init() { pwm_attach(PIN_SERVO, SERVO_FREQ_HZ, 16); shutter_power(false); }
void shutter_set_us(uint16_t us) { pwm_write(PIN_SERVO, us_to_duty(constrain(us, SERVO_US_MIN, SERVO_US_MAX))); }
void shutter_set(ShutterState s, bool wait) { shutter_set_us(s == SHUTTER_OPEN ? cal.shutter_open_us : cal.shutter_closed_us); if (wait) delay(SHUTTER_SETTLE_MS); s_shutter = s; }
void shutter_power(bool on) { if (on) shutter_set(s_shutter, false); else pwm_write(PIN_SERVO, 0); }
ShutterState shutter_state() { return s_shutter; }

// ============================================================ DC motors
static const int IN1[3] = { PIN_FEED_IN1, PIN_NIPE_IN1, PIN_NIPX_IN1 };
static const int IN2[3] = { PIN_FEED_IN2, PIN_NIPE_IN2, PIN_NIPX_IN2 };
void motors_init() { pinMode(PIN_DRV_SLEEP, OUTPUT); digitalWrite(PIN_DRV_SLEEP, LOW);
    for (int m = 0; m < 3; m++) { pwm_attach(IN1[m], MOTOR_PWM_HZ, 8); pwm_attach(IN2[m], MOTOR_PWM_HZ, 8); pwm_write(IN1[m], 0); pwm_write(IN2[m], 0); } }
void motor_run(Motor m, int pwm) { pwm = constrain(pwm, -255, 255);
    if (pwm >= 0) { pwm_write(IN2[m], 0); pwm_write(IN1[m], pwm); } else { pwm_write(IN1[m], 0); pwm_write(IN2[m], -pwm); } }
void motors_sleep(bool sleep) { digitalWrite(PIN_DRV_SLEEP, sleep ? LOW : HIGH); if (!sleep) delay(2); }

// ============================================================ sensors
static int s_sig[N_BEAMS] = {0,0,0,0};
static const int BEAM_PIN[N_BEAMS] = { PIN_BEAM_B, PIN_BEAM_E, PIN_BEAM_S, PIN_BEAM_X };
void sensors_init() { pinMode(PIN_IR_EN, OUTPUT); digitalWrite(PIN_IR_EN, LOW);
    pinMode(PIN_INDEX, INPUT);          // external 10 k pull-down; the index LED is always on
    pinMode(PIN_BUTTON, INPUT_PULLUP); pinMode(PIN_DECK, INPUT_PULLUP); adc_setup(); }
void beams_poll() {
    int on[N_BEAMS] = {0,0,0,0}, off[N_BEAMS] = {0,0,0,0};
    for (int s = 0; s < BEAM_SAMPLES; s++) {
        digitalWrite(PIN_IR_EN, HIGH); delayMicroseconds(BEAM_SETTLE_US);
        for (int b = 0; b < N_BEAMS; b++) on[b] += analogRead(BEAM_PIN[b]);
        digitalWrite(PIN_IR_EN, LOW); delayMicroseconds(BEAM_SETTLE_US);
        for (int b = 0; b < N_BEAMS; b++) off[b] += analogRead(BEAM_PIN[b]);
    }
    for (int b = 0; b < N_BEAMS; b++) { s_sig[b] = (on[b] - off[b]) / BEAM_SAMPLES; jitter_add((uint32_t)(on[b] ^ (off[b] << 12) ^ micros())); }
}
int  beam_signal(Beam b) { return s_sig[b]; }
bool beam_blocked(Beam b) { return s_sig[b] < (int)cal.beam_thresh[b]; }
bool beam_blocked_now(Beam b) { beams_poll(); return beam_blocked(b); }
bool index_active() { return digitalRead(PIN_INDEX) == LOW; }
bool button_down() { return digitalRead(PIN_BUTTON) == LOW; }
float battery_volts() { uint32_t mv = 0; for (int i = 0; i < 8; i++) mv += analogReadMilliVolts(PIN_VBAT); return (mv / 8) * 0.001f * VBAT_DIVIDER * cal.vbat_gain; }
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

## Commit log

2026-09-30 Add complete card shuffler design: docs, math, simulation, CAD, electronics, firmware
    Single-card random-gap insertion shuffler (inside-out Fisher-Yates executed
    physically) for a 52-54 card poker deck, designed for FDM printing and
    hobby parts under $130.
    - docs/01-10: mechanism selection, mathematics (proofs, fault analysis,
    riffle theory, validation plan), mechanical design, electronics and
    battery, BOM, assembly, operation, verification checklist, prototype
    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
    [bom.csv, bushing_bracket.stl, carriage.stl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]
2026-09-30 Redesign around a 54-slot wheel (random slot assignment); archive v1
    Switch the architecture from elevator/blade insertion to a horizontal-axis
    54-slot wheel: each card is pushed into a uniformly random empty slot
    (exact Fisher-Yates), then the wheel is emptied in slot order. Faster
    (est. 40-45 s first build, ~30 s tuned), needs only +/-1 mm positioning,
    fewer actuators, about $7 cheaper.
    - docs/: all ten documents rewritten for the wheel (mechanism selection,
    mathematics with the empty-slot uniformity proof, the sensor-corrected
    neighbour-error invariance and the two-well theorem, mechanical design,
    electronics, BOM, assembly, operation, verification, prototype plan,
    gaps); new dia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
    [base_cover_front.stl, base_cover_rear.stl, base_front.stl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]
2026-10-01 Design review: fix wheel geometry, interlocks and doc errors
    Mechanical (CAD):
    - Seated cards (edge r 85.5) overlapped the feeder plate and beam-E
    bridge; the plate now starts at the nip and beams E/S run obliquely
    between the towers, clear of the swept volume
    - Exit shutter moved inside the shroud as a ramped blade so card edges
    cannot drop into the window and snag; servo pocket in the -Y tower
    - Entry N20 motors passed through the tower; rollers shortened to 64 mm
    - Idler wheels moved over the roller O-rings; spring crossbars added;
    beam B/X detectors mounted in the idler arm boss; ears clear the rails
    - Gate moved out 7 mm to clear the idler pivot; fin tips chamfered
    - Index tab m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
    [base_cover_front.stl, base_cover_rear.stl, base_front.stl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]
2026-10-01 Print-readiness sweep: fix print orientations, chute clash, part counts
    Adds cad/check_printability.py, a slicer-style check (watertight mesh,
    nothing floating, bed fit, support-free overhangs layer by layer), and
    mating-part collision checks.
    Fixes found by it:
    - towers printed on their 4 mm bosses; now outer face down, motor
    standoff split out as motor_mount (4 x M3 x 40 through-bolts)
    - chute floor passed through both tower plates; chute now sits between
    the towers and screws to new tower cheeks from the side
    - wheel printed on a hub boss; -Y boss is now hub_spacer, solid -Y disc,
    hub ribs, pointed fin windows
    - shroud_A was split in two by the window and both shrouds stood on tab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
    [base_cover_front.stl, base_cover_rear.stl, base_front.stl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]
2026-10-07 Open the exit shutter only once the first full slot is at the exit
    run_shuffle() and unload_all() opened the shutter while the wheel was
    still at the last entry (or scan) position. Two cards rest over the
    202-214 deg window there and slide out against the stopped nip, unseen
    by beam X, and the move to the first slot (up to 180 deg) swept every
    occupied slot on its path across the open window.
    Both now bring the first occupied slot to the exit with the shutter
    closed, then open it (unload_open()); the loop's first move is then 0
    steps. unload_all() also closes the shutter before homing, since it can
    follow an ERROR 9 with the shutter left open.
    Docs: unload order in 04 4.7, 06 6.5 step 28 a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
    [shuffler.ino]
